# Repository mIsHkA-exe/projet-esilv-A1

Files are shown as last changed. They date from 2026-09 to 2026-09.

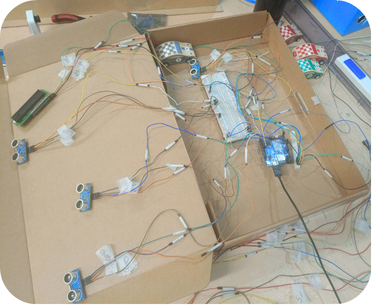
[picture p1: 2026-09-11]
images/wiring-prototype.png

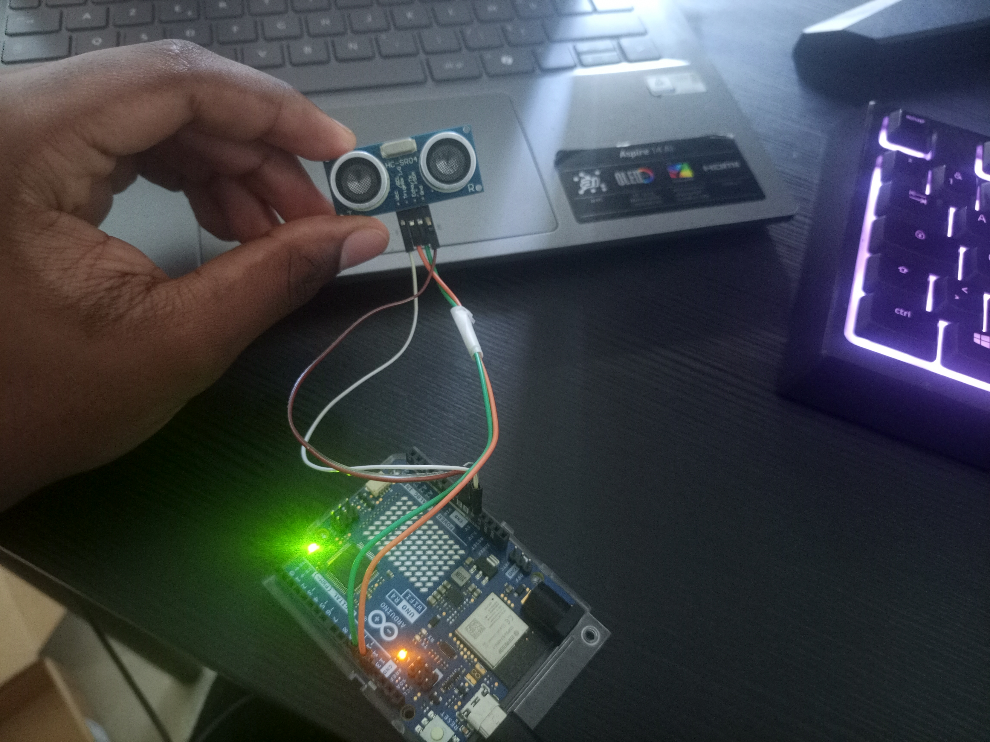
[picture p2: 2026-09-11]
unit-tests-iot/Ultrasons/Montage/Montage.jpg

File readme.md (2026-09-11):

# DAVINCI CUSTOM GARAGE — Smart Parking

> A connected smart parking system combining **web development, IoT, embedded systems, electronics, and real-time data synchronization**.







---

## Table of Contents

* [Project Overview](#project-overview)
* [Objectives](#objectives)
* [System Architecture](#system-architecture)
* [System Workflow](#system-workflow)
* [Web Application](#web-application)
* [Database](#database)
* [REST API](#rest-api)
* [Embedded System](#embedded-system)
* [QR-Code Access Control](#qr-code-access-control)
* [Parking-Space Detection](#parking-space-detection)
* [3D Modeling](#3d-modeling)
* [Simulation and Testing](#simulation-and-testing)
* [Development Challenges](#development-challenges)
* [Project Status](#project-status)
* [Contributions and Suggestions](#contributions-and-suggestions)
* [Budget](#budget)
* [Security and Privacy](#security-and-privacy)
* [Current Limitations](#current-limitations)
* [Future Improvements](#future-improvements)
* [Repository Structure](#repository-structure)
* [Technologies](#technologies)
* [Skills Demonstrated](#skills-demonstrated)
* [Team](#team)
* [Documentation](#documentation)
* [Conclusion](#conclusion)

---

## Project Overview

**DAVINCI CUSTOM GARAGE** is a connected smart parking prototype developed as part of the **Cybersecurity Bachelor's program at ESILV** during the 2025–2026 academic year.

The project combines a **web-based parking reservation platform** with an **automated physical model** representing a connected parking infrastructure.

The main objective is to connect a digital parking management platform with a physical embedded system in order to simulate automated parking management.

### Main Features

The platform allows users to:

* View available parking spaces.
* Reserve a parking space online.
* Receive a unique QR code.
* Use the QR code as an access credential.
* Automatically trigger the parking entrance barrier after validation.
* View parking availability through the web interface.
* Synchronize physical parking-space occupancy with the web application.

The physical prototype detects parking-space occupancy and communicates this information to the web application, allowing the digital and physical states of the parking system to remain synchronized.

---

## Objectives

The project was designed to address several challenges associated with urban parking management.

### Main Objectives

* Reduce the time required to find an available parking space.
* Improve the management of available parking areas.
* Automate access to the parking facility.
* Provide users with updated parking information.
* Synchronize physical infrastructure with a web application.
* Experiment with embedded systems and web technologies.
* Develop a connected system combining electronics, software, databases, and communication protocols.
* Respect a maximum hardware budget of **€150**.

The original project requirements also identified automatic vehicle detection, parking availability information, access control, continuous operation, low energy consumption, and maintainability as major service functions.

---

## System Architecture

The system is organized into three main layers:

```text
┌──────────────────────────────────────────────────┐
│                    USER LAYER                    │
│                                                  │
│          Web Interface / Reservation System      │
└────────────────────────┬─────────────────────────┘
                         │
                         ▼
┌──────────────────────────────────────────────────┐
│                APPLICATION LAYER                 │
│                                                  │
│       Symfony / REST API / Doctrine / MySQL      │
│                                                  │
│  • Users                                         │
│  • Reservations                                  │
│  • QR Codes                                      │
│  • Parking Spaces                                │
│  • Access History                                │
└────────────────────────┬─────────────────────────┘
                         │
                         │ JSON / API
                         ▼
┌──────────────────────────────────────────────────┐
│                 EMBEDDED LAYER                   │
│                                                  │
│          Arduino UNO R4 WiFi + ESP32-CAM         │
│                                                  │
│  • Ultrasonic Sensors                            │
│  • LEDs                                          │
│  • LCD Display                                   │
│  • Servo Motors                                  │
└────────────────────────┬─────────────────────────┘
                         │
                         ▼
                ┌─────────────────┐
                │ Physical Parking│
                └─────────────────┘
```

This architecture enables communication between the web platform and the physical prototype, allowing parking-space information to be transmitted and updated throughout the system.

---

## System Workflow

The general workflow is:

```text
User accesses the web application
              │
              ▼
Checks available parking spaces
              │
              ▼
Makes a reservation
              │
              ▼
System generates a unique QR code
              │
              ▼
User presents QR code at the entrance
              │
              ▼
ESP32-CAM reads the QR code
              │
              ▼
Symfony REST API validates the reservation
              │
        ┌─────┴─────┐
        │           │
      VALID       INVALID
        │           │
        ▼           ▼
 Open barrier   Access denied
        │
        ▼
Vehicle enters the parking
        │
        ▼
Sensor detects vehicle presence
        │
        ▼
Parking-space status is updated
        │
        ▼
Data is transmitted to the server
        │
        ▼
Web interface is updated
```

The objective is to maintain consistency between the physical state of the parking infrastructure and the information displayed on the web application.

---

## Web Application

The web application was developed using the **Symfony PHP framework** and follows an **MVC architecture**.

### Main Features

* Parking-space availability display.
* Online parking reservation.
* Automatic QR-code generation.
* User account management.
* Administration interface.
* Parking-space status management.
* Communication with the embedded infrastructure.
* Real-time synchronization between the physical model and the web platform.

The web application acts as the main digital interface between users and the smart parking system.

---

## Database

The project uses a relational database managed with **MySQL** and **Doctrine ORM**.

The database centralizes the information required for the operation of the system.

### Main Entities

```text
User
 │
 ├── Reservation
 │      │
 │      └── QR Code
 │
 └── Access History

Parking Space
 │
 └── Availability Status
```

### Main Data Categories

* Users
* Reservations
* Parking spaces
* QR codes
* Parking-space status
* Access history

For the academic prototype, fictitious data is used for demonstrations. No real banking information is intended to be stored.

---

## REST API

A **REST API developed with Symfony** provides communication between the web platform and the physical parking prototype.

The API uses **JSON** for data exchange.

### Main Responsibilities

* Validate QR codes.
* Retrieve parking-space status.
* Update parking-space occupancy.
* Receive events generated by the Arduino system.
* Synchronize physical events with the database.
* Provide updated information to the web application.

The API acts as the communication bridge between the embedded system and the application layer.

### Communication Flow

```text
Embedded System
       │
       │ HTTP / JSON
       ▼
Symfony REST API
       │
       ├── QR Code Validation
       │
       ├── Parking Status
       │
       ├── Occupancy Updates
       │
       └── Embedded Events
       │
       ▼
Database
       │
       ▼
Web Application
```

---

## Embedded System

The physical prototype is built around several electronic components.

| Component | Purpose |
| --- | --- |
| **Arduino UNO R4 WiFi** | Main embedded controller |
| **ESP32-CAM** | QR-code reading and recognition |
| **HC-SR04 ultrasonic sensors** | Vehicle presence detection |
| **Infrared sensors** | Entrance and exit detection |
| **Servo motors** | Automated parking barriers |
| **LEDs** | Parking-space status indication |
| **LCD 16x2** | Parking information display |
| **RGB LED strip** | Parking model lighting |
| **Breadboard** | Component integration |
| **Jumper wires** | Electrical connections |

The embedded software is developed using **Arduino IDE and C++**.

---

## QR-Code Access Control

QR-code validation is one of the main access-control mechanisms implemented in the project.

```text
Web Reservation
       │
       ▼
Unique QR Code
       │
       ▼
ESP32-CAM
       │
       ▼
QR Code Recognition
       │
       ▼
Symfony REST API
       │
       ▼
Reservation Validation
       │
   ┌───┴────┐
   │        │
 VALID    INVALID
   │        │
   ▼        ▼
Open     Reject
Barrier  Access
   │
   ▼
Record Access
```

When a valid QR code is detected, the system authorizes access and triggers the opening of the parking barrier.

Invalid QR codes are rejected.

The access event can then be recorded in the database.

---

## Parking-Space Detection

Each parking space is equipped with a sensor designed to detect whether a vehicle is present.

When a vehicle is detected:

1. The physical state of the parking space changes.
2. The corresponding LED indicates the state of the space.
3. The embedded system processes the information.
4. The information is transmitted through the communication layer.
5. The database is updated.
6. The web interface can reflect the new parking status.

The tests conducted during the project demonstrated that the detection mechanism was sufficiently reliable for the scale of the prototype.

---

## 3D Modeling

Before the physical assembly of the prototype, the parking structure was modeled using **SolidWorks**.

The 3D modeling phase was used to design and organize:

* Parking spaces.
* Traffic lanes.
* Entrance and exit barriers.
* Sensor locations.
* Electronic component supports.
* Cable-management structures.
* Protective covers for electronic connections.

The covers were designed to improve the appearance of the prototype while protecting and organizing the wiring.

---

## Simulation and Testing

Several tools were used to validate the system before and during physical implementation.

### Simulation Tools

* **Wokwi**
* **Tinkercad**

These platforms were used to simulate electronic components and validate circuit behavior before working with the physical hardware.

### Physical Testing

The following components were tested:

* Ultrasonic sensors
* Infrared sensors
* LEDs
* Servo motors
* LCD display
* ESP32-CAM
* Arduino UNO R4 WiFi

### Functional Tests

| Test | Result |
| --- | --- |
| Vehicle detection | Successful |
| Parking-space status update | Successful |
| Valid QR-code recognition | Successful |
| Invalid QR-code rejection | Successful |
| Automatic barrier opening | Successful |
| Automatic barrier closing | Successful |
| Database synchronization | Successful |
| Web interface synchronization | Successful |
| Web ↔ Embedded communication  | Functional |

The tests demonstrated that the main components of the prototype could communicate and operate together according to the project's objectives.

---

## Development Challenges

The development of **DAVINCI CUSTOM GARAGE** involved several technical challenges.

One of the main difficulties was implementing reliable **real-time parking-space display and synchronization** between the physical prototype and the web application.

### Symfony ↔ Arduino Synchronization

The communication between the Symfony application, REST API, and Arduino embedded system required several development and testing phases.

Particular difficulties were encountered in:

* Transmitting information between the web application and the embedded system.
* Synchronizing the actual state of parking spaces with the information displayed on the website.
* Updating parking availability in real time.
* Maintaining consistency between the database, Symfony, and Arduino.
* Handling events generated by physical sensors.
* Managing communication between multiple hardware and software components.

### Real-Time Parking Display

The expected communication chain was:

```text
Parking Sensors
       │
       ▼
Arduino
       │
       ▼
Communication Layer
       │
       ▼
Symfony REST API
       │
       ▼
Database
       │
       ▼
Web Interface
```

Maintaining synchronization throughout this entire chain proved to be one of the more challenging aspects of the project.

Although the prototype demonstrates the overall concept, this part of the system remains an important area for future improvement.

---

## Project Status

**DAVINCI CUSTOM GARAGE** is an evolving academic project.

The current version demonstrates the main concept of a connected smart parking system, but several technical aspects can still be improved.

### Planned Improvements

* Improve Symfony-to-Arduino communication.
* Optimize the REST API.
* Improve real-time data synchronization.
* Reduce synchronization delays.
* Improve code structure and maintainability.
* Improve database management.
* Strengthen system reliability.
* Improve UI/UX.
* Add new platform features.
* Improve the overall user experience.

The project should therefore be considered an **active prototype rather than a final production-ready solution**.

---

## Contributions and Suggestions

We are open to suggestions and ideas that could help improve the project.

We particularly welcome proposals related to:

* Code optimization
* Software architecture
* API design
* Symfony development
* Arduino communication
* Real-time data management
* Database optimization
* Cybersecurity
* UI/UX improvements
* User experience
* Embedded-system optimization
* New features and functionalities

If you have an idea that could improve the project, feel free to open an **Issue** or submit a **Pull Request**.

Any constructive contribution aimed at improving the code, reliability, architecture, security, or user experience is welcome.

---

## Budget

The project was developed under a strict hardware budget constraint of **€150**.

### Final Hardware Budget

| Category  | Amount |
| --- | ---: |
| **Total** | **€142.74 including VAT** |

The hardware components included:

* Arduino board
* ESP32-CAM
* Ultrasonic sensors
* Infrared sensors
* Servo motor
* LEDs
* LCD display
* Breadboard
* Jumper wires
* RGB LED strip

The project therefore remained within the defined budget constraint.

---

## Security and Privacy

Because this project was developed as part of a **Cybersecurity Bachelor's program**, security and data protection were considered during the design process.

### Security and Privacy Considerations

* Use of fictitious data for demonstrations.
* No real banking information.
* Consideration of GDPR requirements.
* Consideration of CNIL recommendations.
* Server-side validation of QR-code access.
* Controlled access to the physical parking.
* Centralized management of reservations and access information.

The project documentation also identifies electrical safety and applicable infrastructure regulations as important constraints for a real-world implementation.

---

## Current Limitations

Several limitations remain in the current prototype:

* Sensor accuracy can be affected by vehicle positioning and environmental conditions.
* The prototype operates at a small physical scale.
* QR-code recognition depends on lighting conditions and camera distance.
* The architecture has not yet been tested with a large number of simultaneous users.
* Real-world network availability requirements have not been fully addressed.
* The current real-time synchronization mechanism still requires optimization.
* Communication between the embedded system and the web application can be further improved.
* The current UI can be enhanced to provide a better user experience.

These limitations provide several opportunities for future development.

---

## Future Improvements

### Artificial Intelligence

AI-based algorithms could be integrated to predict parking occupancy and optimize the allocation of available spaces.

### Automatic License Plate Recognition

License-plate recognition could complement or eventually replace QR-code-based access control.

### Mobile Application

A dedicated mobile application could provide users with easier access to reservations and real-time parking availability.

### Cloud Infrastructure

Cloud-based services could improve scalability, availability, monitoring, and remote management.

### Automated Payments

A secure automated payment system could bring the prototype closer to a real-world commercial parking solution.

### Advanced Monitoring

Additional monitoring and analytics could be implemented to provide administrators with detailed information about parking usage and system performance.

---

## Repository Structure

The recommended repository structure is:

```text
davinci-custom-garage/
│
├── README.md
│
├── web/
│   ├── src/
│   ├── templates/
│   ├── config/
│   └── ...
│
├── api/
│   └── ...
│
├── embedded/
│   ├── arduino/
│   └── esp32-cam/
│
├── database/
│   └── ...
│
├── hardware/
│   ├── schematics/
│   └── components/
│
├── 3D/
│   └── solidworks/
│
├── simulation/
│   ├── wokwi/
│   └── tinkercad/
│
├── documentation/
│   ├── cahier-des-charges/
│   └── rapport/
│
└── assets/
    ├── images/
    └── diagrams/
```

---

## Technologies

### Software

* PHP
* Symfony
* Doctrine ORM
* MySQL
* SQL
* REST API
* JSON
* C++
* Arduino IDE
* Python

### Hardware

* Arduino UNO R4 WiFi
* ESP32-CAM
* HC-SR04 ultrasonic sensors
* Infrared sensors
* Servo motors
* LEDs
* LCD 16x2
* RGB LED strip
* Breadboard
* Jumper wires

### Design and Simulation

* SolidWorks
* Wokwi
* Tinkercad

---

## Skills Demonstrated

This project provided practical experience in several technical areas:

* Web application development
* PHP and Symfony development
* REST API development
* Relational database design
* SQL and Doctrine ORM
* Embedded programming
* C++ programming
* Arduino development
* ESP32 integration
* Sensor integration
* Electronic circuit design
* Real-time communication
* QR-code-based access control
* System integration
* 3D modeling
* Hardware simulation
* Technical testing
* Debugging and troubleshooting
* Team collaboration
* Project management

---

## Team

### Team 108 — ESILV

* **Kyllian Siewe Tiague**
* **Vikash Srikanthan**
* **Abdulrahman El Najjar**
* **Adam Tiss**

**Academic project developed as part of the Cybersecurity Bachelor's program at ESILV, 2025–2026.**

---

## Documentation

The project documentation includes:

* Project requirements specification
* Functional analysis
* Technical analysis
* Structural analysis
* Hardware component documentation
* Purchase order and budget documentation
* Web application documentation
* Embedded-system documentation
* Database documentation
* Testing and validation results
* Project development report

---

## Conclusion

**DAVINCI CUSTOM GARAGE** is an academic prototype demonstrating how **web technologies, embedded systems, electronics, databases, and connected infrastructure** can be combined to create a smart parking solution.

The project implements several key concepts:

* Online parking reservation
* QR-code-based access control
* Automated barriers
* Vehicle detection
* Parking-space monitoring
* REST API communication
* Database synchronization
* Web-to-hardware communication
* Real-time parking information

The project also provided practical experience in identifying and solving integration problems between software and hardware components.

Although several aspects of the system still require optimization — particularly **real-time display and synchronization between Symfony and the Arduino-based infrastructure** — the project provides a functional foundation for future development.

The team intends to continue improving the code, communication architecture, system reliability, and UI/UX.

**DAVINCI CUSTOM GARAGE is therefore not considered a finished product, but an evolving prototype open to optimization, experimentation, and future contributions.**

---

## Academic Project

**DAVINCI CUSTOM GARAGE — Smart Parking**

**ESILV — Cybersecurity Bachelor's Program**

**Academic Year 2025–2026**

**Team 108**

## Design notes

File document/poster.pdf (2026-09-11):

# DAVINCI CUSTOM GARAGE

LE FUTUR DU STATIONNEMENT INTELLIGENT

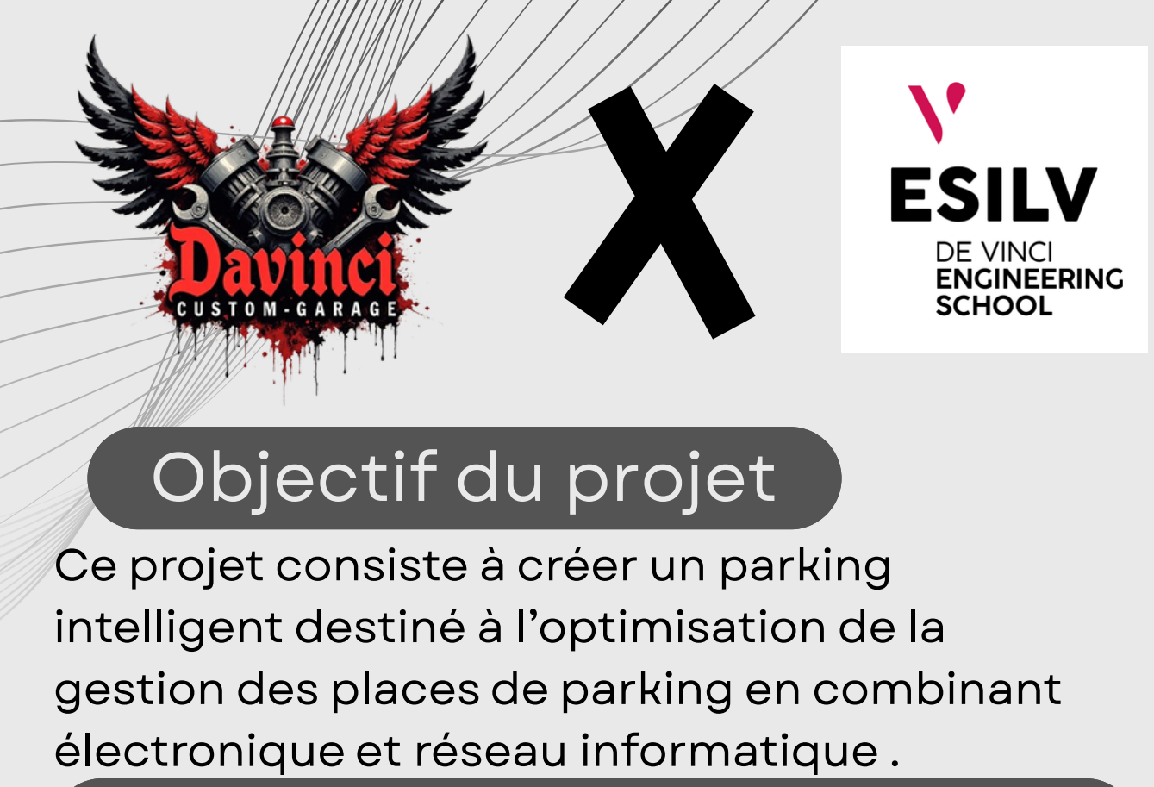
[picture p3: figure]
Objectif du projet; Ce projet consiste à créer un parking; électronique et réseau informatique .

intelligent destiné à l’optimisation de la gestion des places de parking en combinant

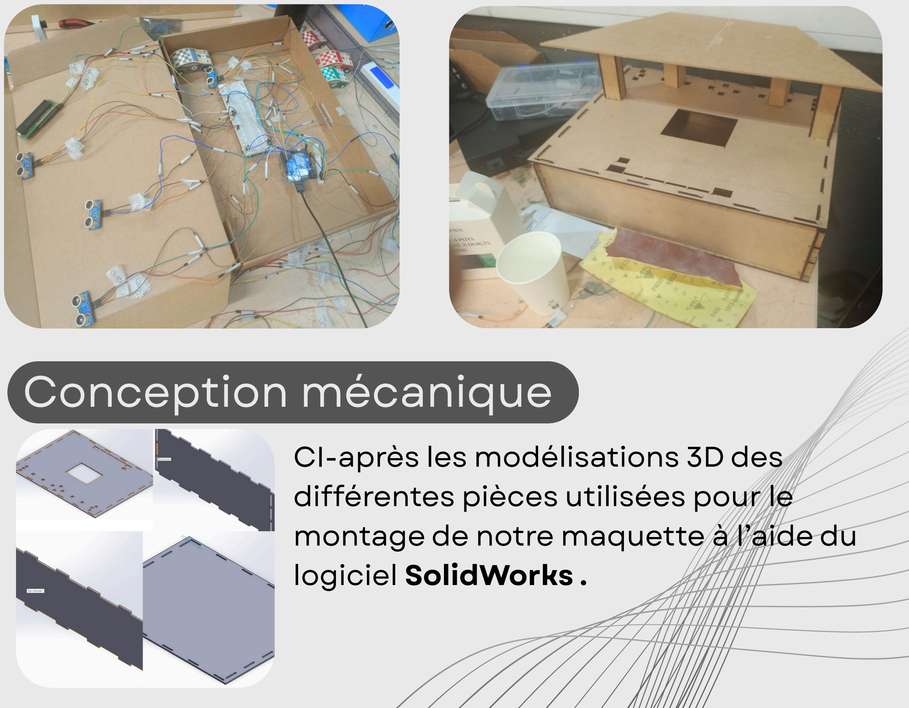
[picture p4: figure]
Conception mécanique; CI-après les modélisations 3D des différentes pièces utilisées pour le montage de notre maquette à l’aide du logiciel SolidWorks .

## Objectif du projet

## Etude du cahier des charges

Il s’agit dans ce projet de concevoir un dispositif opérationel en fonction des beoins fonctionnels et des contraintes techniques imposées avec un budget de 150 euros .

## Simulation électronique & Prototype

Simulation de la détection des places avec les
capteurs à ultrasons et impression du prototype

## Contribution individuelle

SieweTiague Kyllian : conception mécanique , réalisation des prototypes et maintenance logiciel
Srikanthan Vikash : Gestion de la décoration de la maquette et de la rédaction des documents de synthèse El Najjar Abdulrahman : Réalisation du poster et contribution à la réalisation de la maquete
Tiss Adam : Contribution à la réalisation de la maquette et aux tests des systèmes .

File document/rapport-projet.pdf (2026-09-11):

# Rapport de Projet : Conception et Réalisation d'un Système de Stationnement Intelligent Connecté

Membre de l’équipe :

Nom | Prenom
Siewe Tiague | Kyllian
Srikanthan | Vikash
El Najjar | Abdulrahman
Tiss | Adam

Sommaire :

Les études sur la mobilité urbaine montrent qu’un conducteur peut consacrer entre 10 et 20 minutes à la recherche d’une place de stationnement en zone urbaine dense. À l’échelle annuelle, cette perte de temps représente plusieurs dizaines d’heures improductives

I - INTRODUCTION GÉNÉRALE

### 1.1 Cadre et contexte académique

Dans le cadre de notre cursus Bachelor en Cybersécurité pour l’année académique 2025–2026 à l’ESILV, nous avons été amenés à concevoir un système de stationnement intelligent combinant électronique analogique et numérique, systèmes embarqués et développement web pour la gestion automatisée d’un parking connecté.

Ce projet pédagogique s’inscrit dans une démarche disciplinaire mobilisant des compétences en programmation, réseaux, cybersécurité, bases de données et électronique embarquée. L’objectif principal consiste à développer, dans un délai défini, une solution autonome capable d’assurer une communication en temps réel entre une infrastructure physique intelligente et une plateforme web de gestion.

Au-delà de l’aspect technique, ce projet vise également à nous confronter aux problématiques concrètes liées à la conception de systèmes connectés, notamment en matière d’automatisation, de gestion des données, de sécurité des accès et d’optimisation des infrastructures urbaines.

### 1.2 La problématique sociale et environnementale

L’évolution démographique et l’urbanisation croissante des grandes métropoles s’accompagnent d’une augmentation constante du trafic automobile mondial. Dans ce contexte, la gestion des infrastructures de stationnement représente aujourd’hui un enjeu majeur pour les collectivités et les usagers.

Trouver une place de parking disponible est devenu une source urbaine importante .Dans les zones fortement fréquentées, les automobilistes passent plusieurs minutes à circuler à faible vitesse dans le seul but de rechercher un emplacement libre. Cette situation engendre de nombreuses conséquences à la fois économiques, environnementales et sociétales.

Perte de temps
Les études sur la mobilité urbaine montrent qu’un conducteur peut consacrer entre 10 et 20 minutes à la recherche d’une place de stationnement en zone urbaine dense. À l’échelle annuelle, cette perte de temps représente plusieurs dizaines d’heures improductives pour un usager régulier.

Impact environnemental
La circulation répétitive des véhicules à faible allure provoque une surconsommation importante de carburant. Les nombreux arrêts, redémarrages et ralentissements entraînent une augmentation significative des émissions de gaz à effet de serre, notamment du dioxyde de carbone (CO₂). À grande échelle, ce phénomène contribue directement à la pollution atmosphérique et à la dégradation de l’environnement urbain.

Impact sociétal
La difficulté à trouver rapidement une place de stationnement constitue également une source récurrente de stress, de frustration et de fatigue pour les conducteurs. Cette problématique affecte la qualité de vie des usagers et participe à la saturation générale des centres urbains.

Face à ces constats, le développement de solutions de stationnement intelligentes apparaît comme une réponse technologique pertinente permettant d’améliorer la fluidité urbaine, de réduire les émissions polluantes et d’optimiser l’utilisation des espaces disponibles.

### 1.3 L'approche globale : DAVINCI CUSTOM GARAGE (Notre parking)

Pour répondre à cette problématique,nous avons imaginé une solution globale et intelligente découpée en deux piliers technologiques majeurs en parfaite synergie :

- L'interface logicielle (Le Site Web) : Développée à l'aide du framework PHP Symfony, cette plateforme permet aux clients d'anticiper leur déplacement. L'utilisateur peut vérifier la disponibilité et effectuer une réservation en ligne. Le système génère alors un QR code unique, tracé et sécurisé dans une base de données, qui servira de droit d'accès physique.
- L'infrastructure physique (La Maquette Connectée) : Afin de matérialiser visuellement notre concept, nous concevons une maquette automatisée à partir d'un microcontrôleur Arduino R4 et d'un module ESP32-CAM. Ce système gère l'accueil des véhicules par lecture du QR code, l'ouverture automatisée des barrières, et s'appuie sur des capteurs embarqués pour surveiller en temps réel l'occupation des places de stationnement. Toute modification physique de l'état d'une place met instantanément à jour la base de données du site web.

II - CAHIER DES CHARGES

### 2.1 Périmètre et Objectifs du Système

Le projet a pour objectif de concevoir et de réaliser un prototype fonctionnel de stationnement intelligent. Le périmètre de cette étude s'articule autour de trois axes interconnectés :

- L'application Web de gestion : Une interface utilisateur permettant la consultation en temps réel de la disponibilité des places et la réservation à distance, complétée par une interface d'administration pour la supervision globale des données.
- La maquette physique : Une infrastructure miniature automatisée simulant l'accès physique, le contrôle des barrières et la surveillance des emplacements.
- La passerelle de communication : Un système d'échange bidirectionnel en temps réel permettant à la maquette de mettre à jour la base de données centrale dès qu'un changement d'état physique survient sur une place.

### 2.2 Analyse des Besoins (Besoins Fonctionnels)

Pour répondre efficacement aux attentes des usagers et des administrateurs, le système doit couvrir les besoins fonctionnels suivants :

- Réservation et sécurisation des accès : L'utilisateur doit pouvoir réserver sa place en ligne et obtenir un QR code unique et sécurisé (généré via Symfony). Ce code sert de droit d'accès exclusif à l'entrée du parking.
- Contrôle automatisé des flux : À l'entrée, le module ESP32-CAM doit lire et valider le QR code afin de déclencher automatiquement l'ouverture de la barrière via un servomoteur.
- Détection autonome de présence : Chaque place du parking doit être équipée de capteurs (infrarouges ou ultrasoniques) capables de détecter de manière continue et autonome l'occupation d'un emplacement par un véhicule.
- Signalisation visuelle locale : Le système doit guider visuellement l'usager dans la maquette grâce à des indicateurs lumineux (une LED s'allume pour indiquer qu'une place est occupée) et un écran LCD affichant un message d'accueil ou le nombre de places restantes.
- Actualisation en temps réel : L'état de disponibilité des places (libre/occupée) doit être synchronisé instantanément avec la base de données pour être consultable sur le site internet.

### 2.3 Contraintes du Projet

La conception de la solution DAVINCI CUSTOM GARAGE est soumise à plusieurs exigences et restrictions strictes :

- Contraintes Économiques (Budget) : Le coût global pour l'achat des composants matériels de la maquette (carte Arduino R4, module ESP32-CAM, capteurs, actionneurs) est strictement limité à un budget maximal de 150 €. Cela impose une sélection rigoureuse de composants à la fois économiques, fiables et optimisés.
- Contraintes Techniques et Matérielles : L'architecture matérielle repose obligatoirement sur l'utilisation d'une carte microcontrôleur principale Arduino R4 WiFi et d'un module ESP32-CAM pour la brique de vision. L'ensemble des développements embarqués doit être réalisé via l'IDE Arduino.
- Contraintes Logicielles : La plateforme web de gestion et l'API de communication doivent être exclusivement développées avec le framework PHP Symfony, en exploitant l'ORM Doctrine et le langage SQL pour la persistance des données.
- Contraintes de Sécurité et Confidentialité (RGPD) : S'agissant d'un projet académique en Cybersécurité, aucune donnée bancaire ou personnelle réelle ne doit être stockée. Le système doit utiliser des outils de génération de données fictives (Fakers) pour simuler les transactions et les profils d'utilisateurs en toute sécurité.
- Contraintes de Fiabilité et Performance : Le traitement des informations et la détection doivent être rapides et précis afin d'éviter tout blocage des barrières ou toute divergence d'information entre la maquette et l'interface Web.

### 2.4 Caractérisation des Fonctions de Service

Pour guider la phase de développement, les fonctions de service du projet ont été hiérarchisées selon leur niveau de priorité:

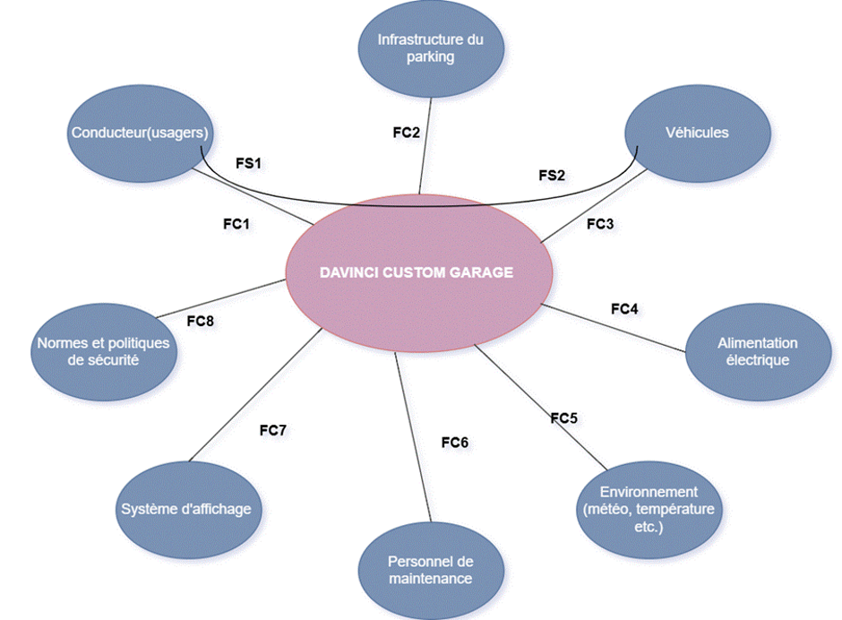
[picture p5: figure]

Figure 2.4 : Caractérisation des fonctions de services
III - CONCEPTION DE LA SOLUTION

### 3.1 Architecture Générale du Système

La solution DAVINCI CUSTOM GARAGE repose sur une architecture hybride associant une infrastructure physique électronique et une plateforme web. L'ensemble des composants communiquent afin de garantir une gestion automatisée et synchronisée du stationnement.

Code | Fonction de Service
FP1 | Détecter automatiquement la présence des véhicules sur les places
FP2 | Informer les usagers sur l’état des places disponibles (Web/LCD)
FP3 | Sécuriser et contrôler l'accès à l'entrée (Validation du QR code)
FP4 | Assurer le fonctionnement en continu et la fiabilité des alertes
FP5 | Guider les usagers vers une place libre (Signalisation par LED)
FP6 | Optimiser la consommation énergétique des composants électroniques
FP7 | Permettre une maintenance simple et une modularité du câblage

Le système est composé de trois couches principales :

- La couche utilisateur : constituée du site web développé sous Symfony, elle permet aux clients de consulter les disponibilités du parking, de réserver une place et de recevoir un qr code unique.
- La couche applicative : représentée par le serveur web et la base de données. Cette couche assure le stockage des réservations, la gestion des utilisateurs, la génération des qr codes ainsi que la synchronisation des informations provenant des cartes électroniques de la maquette .
- La couche embarquée : composée de la carte Arduino UNO R4 WiFi, des modules ESP32-CAM, des capteurs de présence, des LEDs, de l'écran LCD et des servomoteurs. Cette couche gère les interactions physiques avec les véhicules et transmet les données vers le serveur.

Le principe de fonctionnement repose sur un échange permanent d'informations entre la maquette et l'application web afin de garantir une cohérence en temps réel des données de stationnement.

### 3.2 Description de l'Architecture Matérielle

L'infrastructure physique du parking intelligent est conçue autour de plusieurs composants électroniques complémentaires notamment :

→ Arduino UNO R4 WiFi
La carte Arduino UNO R4 WiFi constitue le cœur du système embarqué. Elle assure la collecte des données provenant des capteurs, le pilotage des actionneurs et la communication avec le serveur distant via le réseau Wi-Fi.

→ ESP32-CAM

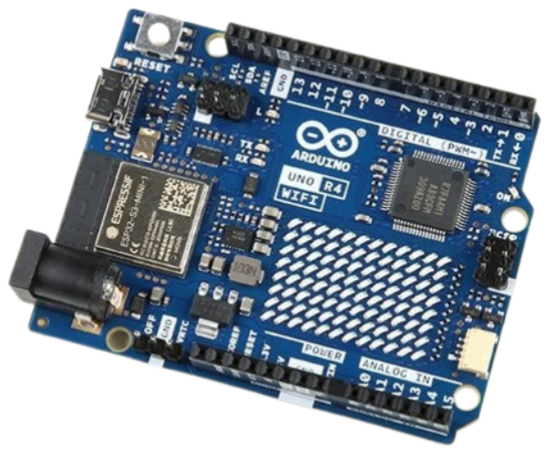
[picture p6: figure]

Le module ESP32-CAM est chargé de la lecture et de la reconnaissance des QR codes présentés à l'entrée du parking. Après validation du code auprès de la base de données, il autorise ou refuse l'accès au véhicule. Un autre module ESP32 est utilisé pour la gestion des actionneurs de manière générale .

→ Capteurs de présence

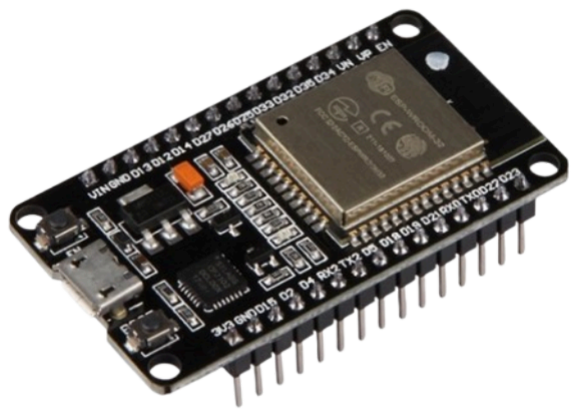
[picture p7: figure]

Chaque place de stationnement est équipée d'un capteur ultrason permettant de détecter la présence ou l'absence d'un véhicule. Ces informations sont transmises à l'Arduino afin de mettre à jour l'état des places.

→ Servomoteurs
Les servomoteurs simulent les barrières d'entrée et de sortie du parking. Leur ouverture est déclenchée automatiquement lorsqu'un QR code valide est détecté.

→ Écran LCD
L'écran LCD affiche différentes informations utiles aux utilisateurs, notamment le nombre de places disponibles ainsi que des messages de bienvenue .

→ LED de signalisation

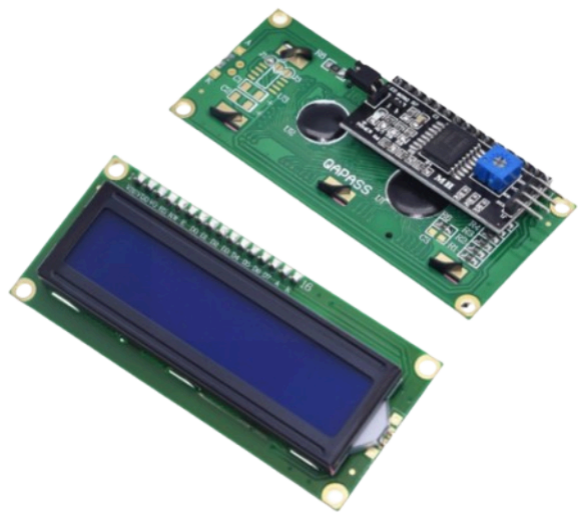
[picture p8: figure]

Des LEDs permettent de représenter visuellement l'état des places de stationnement. On a utilisé un code couleur composé de 3 couleurs qui permettent de distinguer visuellement l’état des places .

### 3.3 Description de l'Architecture Logicielle

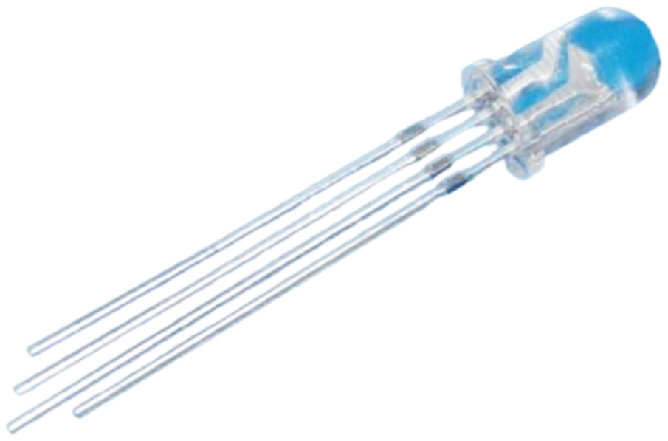
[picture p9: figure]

Le développement logiciel repose sur plusieurs technologies complémentaires . Il s’agit principalement de :

→ Framework Symfony
Symfony a été retenu pour développer l'ensemble de l'application web. C’est un FrameWork PHP qui permet la gestion de l'architecture MVC de toute l’application Web avec la manipulation de Doctrine , Composer et bien d’autres librairies .

→ Base de données
La persistance des données est assurée par une base de données relationnelle gérée via Doctrine ORM et alimenté par Sql . Les principales informations stockées concernent :
- Les utilisateurs
- Les réservations
- Les QR codes générés
- L'état des places de stationnement
- Les historiques d'accès
- Les places

### 3.4 Diagramme Fonctionnel du Système

Le fonctionnement global du système peut être résumé selon les étapes suivantes :

1. L'utilisateur consulte les places disponibles sur le site web.
2. Il effectue une réservation.
3. Le système génère un QR code unique.
4. À l'arrivée du véhicule, l'ESP32-CAM scanne le QR code.
5. Le serveur vérifie la validité de la réservation.
6. Si la réservation est valide, la barrière s'ouvre automatiquement.
7. Le véhicule se gare sur une place disponible.
8. Le capteur détecte l'occupation de la place.
9. L'information est transmise à la base de données.
10.Le site web met à jour instantanément le nombre de places disponibles.

Cette architecture garantit une gestion automatisée, sécurisée et temps réel de l'ensemble du parking connecté.

IV - RÉALISATION ET DÉVELOPPEMENT

### 4.1 Développement de l'interface web

L'interface web constitue le point central d'interaction entre les utilisateurs et le système de stationnement intelligent DAVINCI CUSTOM GARAGE. Son développement a été réalisé à l'aide du framework Symfony. L'application permet aux utilisateurs de consulter en temps réel la disponibilité des places de stationnement, d'effectuer une réservation et d'obtenir un QR code servant de moyen d'identification lors de l'accès au parking.
L'architecture du projet suit le modèle MVC (Modèle - Vue - Controller), permettant une séparation claire entre la logique métier, les données et l'interface utilisateur.

Les principales fonctionnalités développées sont :

- Consultation des places disponibles
- Réservation d'une place de stationnement
- Génération automatique de QR codes
- Gestion des comptes utilisateurs
- Interface d'administration
- Affichage en temps réel de l'état du parking.

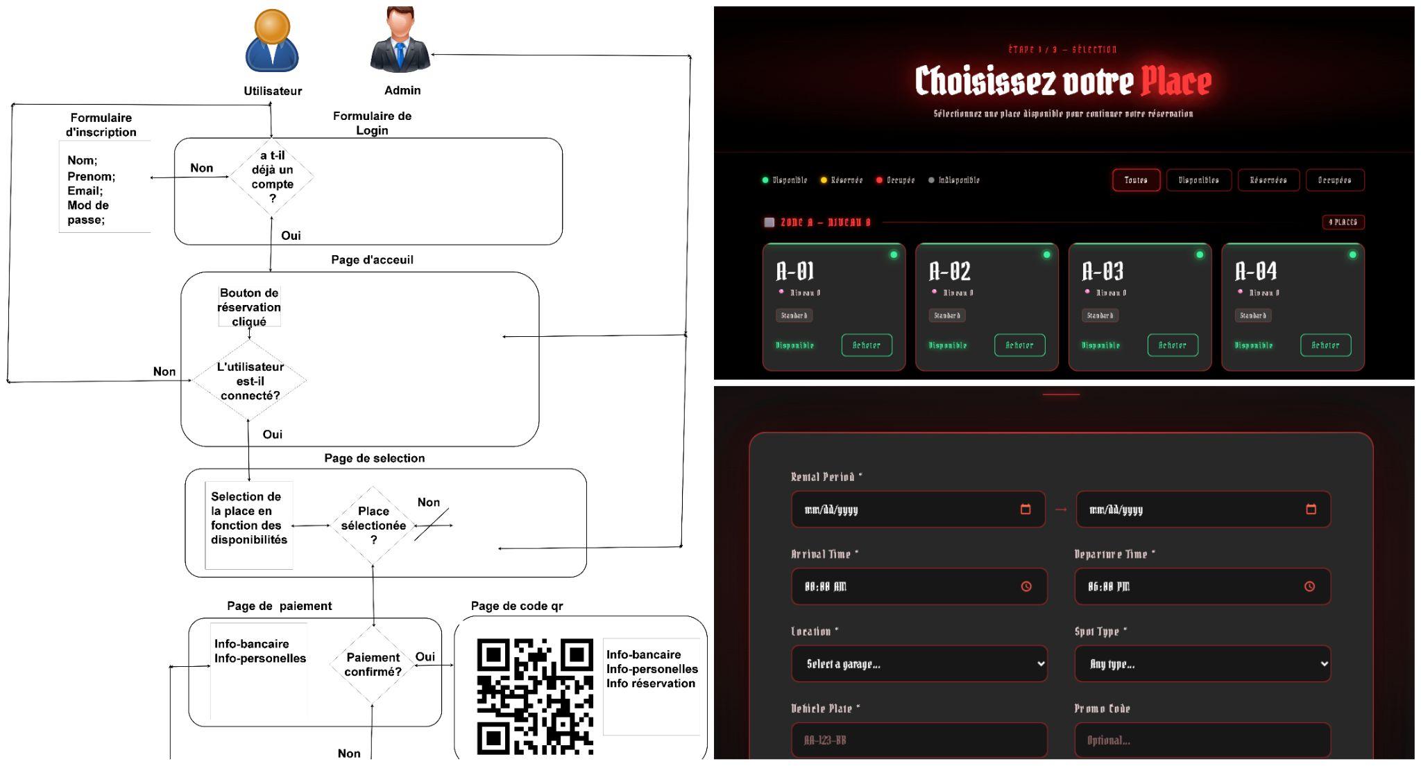
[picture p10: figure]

Figure 4.1 : capture Symfony de l’interface Web de réservation

### 4.2 Mise en place de la base de données

Afin d'assurer la gestion des informations du système, une base de données relationnelle a été mise en place à l'aide de MySQL et administrée via Doctrine ORM.Cette base de données centralise l'ensemble des informations nécessaires au fonctionnement du parking connecté.
Les principales entités implémentées sont :

Utilisateurs
Cette table contient les informations relatives aux utilisateurs enregistrés sur la plateforme :
- Identifiant unique
- Nom
- Adresse électronique
- Mot de passe sécurisé
- Rôle utilisateur

Réservations

Cette table stocke les réservations effectuées par les utilisateurs :

- Identifiant de réservation
- Utilisateur associé
- Place réservée
- Date et heure
- Statut de réservation

Places
Cette entité représente les emplacements disponibles dans le parking :
- Numéro de place
- État (libre ou occupée)

QR Codes
Chaque réservation génère un QR code unique permettant l'accès au parking et les informations enregistrées comprennent :
- Identifiant du QR code
- Réservation associée
- Date de création
- Statut de validité

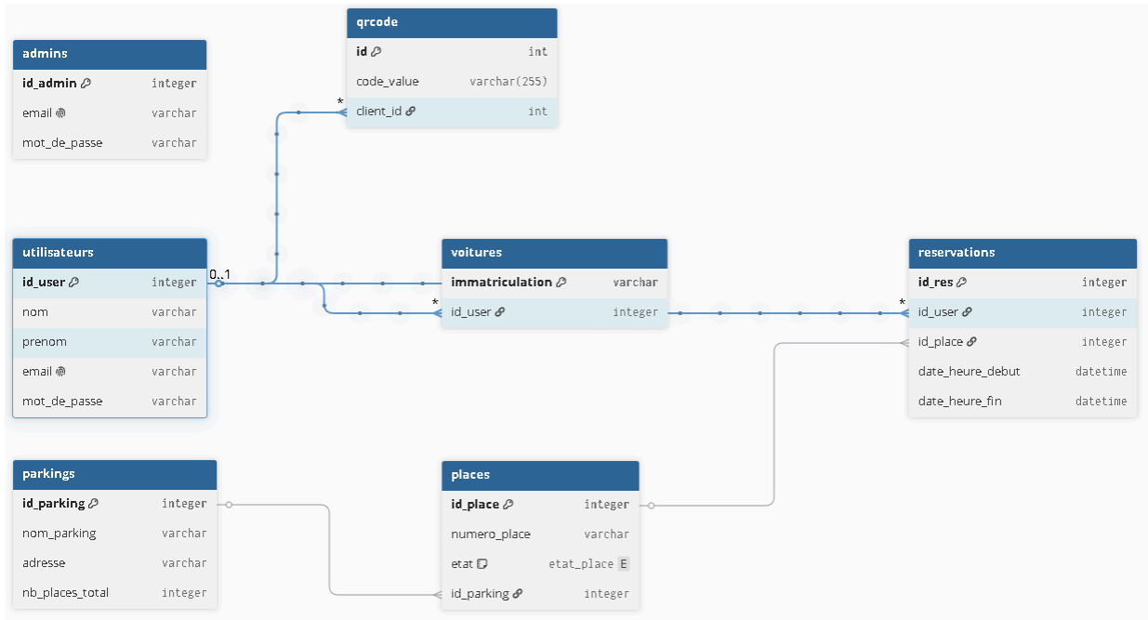
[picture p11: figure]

Figure 4.2 : Captures d’écran du diagramme Entités/Association de la base de données

### 4.3 Développement de l'API de Communication entre Symfony et le parking

Afin de permettre les échanges entre la maquette physique et l'application web, une API REST a été développée sous Symfony. Cette API joue un rôle essentiel dans la synchronisation des informations entre les composants matériels et la plateforme de gestion.
Les principales opérations réalisées par l'API sont :
- Vérification de la validité d'un QR code ;
- Consultation de l'état des places ;
- Mise à jour de l'occupation des emplacements ;
- Transmission des événements provenant de l'Arduino ;
- Actualisation des données affichées sur le site web.

Les échanges sont réalisés au format JSON afin de garantir une communication légère, rapide et compatible avec les systèmes embarqués.

### 4.4 Réalisation de la partie embarquée

La partie embarquée repose sur une carte Arduino UNO R4 WiFi associée à d’autres cartes électroniques notamment deux ESP32 L'Arduino assure la gestion des capteurs, des actionneurs et des communications avec le serveur distant.
Le programme embarqué a été développé à l'aide de l'environnement Arduino IDE en langage C++.

Les principales fonctions implémentées sont :

- Lecture des capteurs de présence (Capteur à ultrason HC-SR04)
- Gestion des LED de signalisation
- Contrôle des servomoteurs
- Affichage des informations sur l'écran LCD
- Synchronisation avec la base de données.

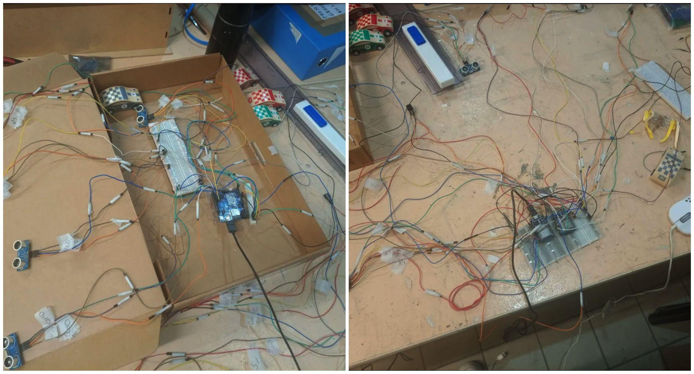
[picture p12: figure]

Figure 4.1 : Câblage des composants sur la carte Arduino

### 4.5 Intégration du Module ESP32-CAM

Le module ESP32-CAM est chargé de la lecture et de la reconnaissance des QR codes utilisés pour le contrôle d'accès. Lorsqu'un utilisateur présente son QR code à l'entrée du parking, l'image est analysée par le un script python qui extrait les informations nécessaires à l'identification de la réservation.
Le code décodé est ensuite ensuite transféré au serveur Symfony pour par une méthode POST pour passer à la vérification

Si la réservation est valide :

- la barrière s'ouvre automatiquement
- l'accès est enregistré dans la base de données
- l'utilisateur est autorisé à stationner

Dans le cas contraire, l'accès est refusé et un message d'erreur est affiché.

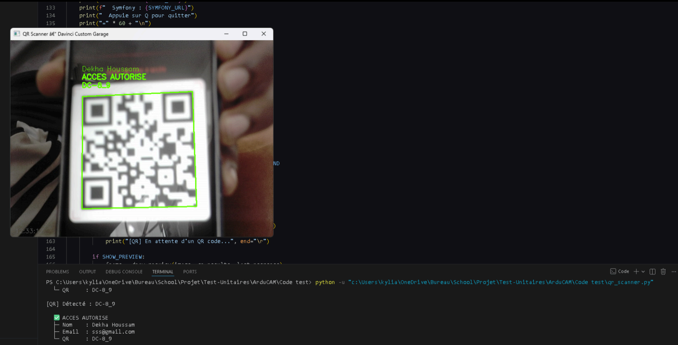
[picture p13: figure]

Figure 4.5 : Lecture de code qr par la ArduCam

### 4.6 Modélisation 3D de la Maquette

Avant la phase de fabrication et d'assemblage, une étape de modélisation 3D a été réalisée afin de concevoir la structure physique du parking intelligent. Cette démarche a permis de visualiser l'organisation générale du système, d'anticiper l'intégration des différents composants électroniques et d'optimiser l'agencement de la maquette.

La modélisation a été effectuée à l'aide d'un logiciel de conception SolidWorks. Elle a permis de représenter les caches des différents éléments constituant le parking, notamment les voies de circulation, les places de stationnement, les barrières d'accès, les emplacements des capteurs ainsi que les supports destinés aux cartes électroniques.

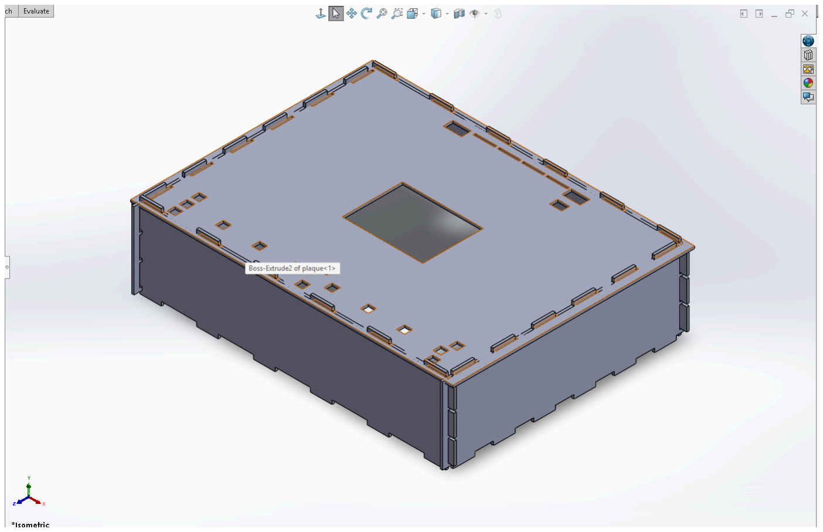
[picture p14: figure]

Figure 4.6 : Modélisation 3D complète du parking intelligent DAVINCI CUSTOM GARAGE

Dans le cadre de la réalisation de la maquette, plusieurs caches ont été modélisées en 3D afin de dissimuler les câbles reliant les capteurs aux cartes électroniques. Cette démarche avait pour objectif d'améliorer l'esthétique générale du prototype tout en protégeant les connexions contre d'éventuelles détériorations ou déconnexions accidentelles.

Ces éléments ont été conçus sur mesure afin de s'adapter aux dimensions de la maquette et au positionnement des différents capteurs. Les caches permettent ainsi de guider proprement le cheminement des câbles sous la structure du parking, tout en conservant un accès simple pour les opérations de maintenance ou de modification du câblage.

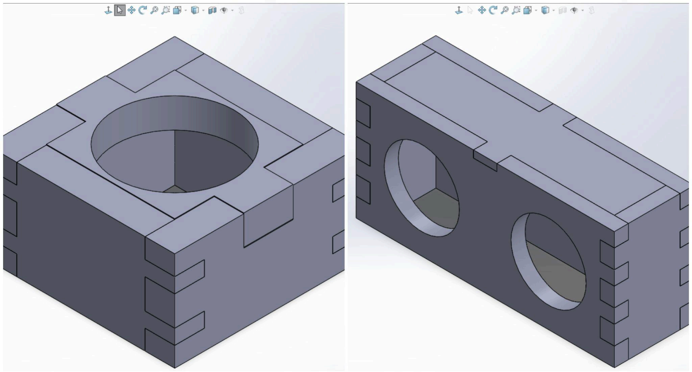
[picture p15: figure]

Figure 4.6.1 : Modélisation des caches des composants

V - TESTS ET RÉSULTATS

### 5.1 Objectifs des Tests

Une fois le développement de l'application web et de la maquette électronique terminé, plusieurs tests ont été réalisés afin de vérifier le bon fonctionnement de l'ensemble du système.

Ces tests avaient pour objectif de valider :

- le fonctionnement des capteurs de présence ;
- la communication entre les composants électroniques ;
- la lecture des QR codes ;
- l'ouverture automatique des barrières ;
- la synchronisation avec la base de données ;
- la mise à jour en temps réel des informations affichées sur le site web.

### 5.2 Environnement de Test

Afin de limiter les risques d'erreur lors du développement, plusieurs outils de simulation ont été utilisés avant l'implémentation sur le matériel réel.

Simulation électronique
La conception des circuits et la validation des branchements ont été réalisées à l'aide des plateformes de simulation électronique :
- TinkerCad
- Wokwi

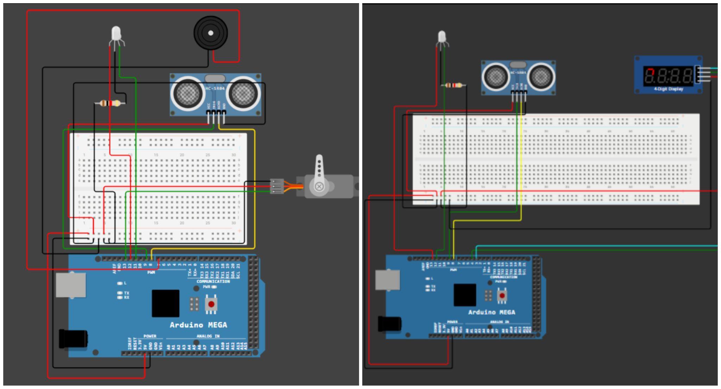
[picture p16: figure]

Figure 5.1 : Simulation des composants sur Wokwi

Ces outils ont permis de tester le comportement des composants sans nécessiter immédiatement le matériel physique.

Tests sur matériel réel
Après validation des simulations, les différents composants ont été assemblés sur la maquette afin de vérifier leur comportement dans des conditions proches d'une utilisation réelle.

Les essais ont porté sur :

- les capteurs ultrasoniques ;
- les LEDs de signalisation ;
- les servomoteurs ;
- l'écran LCD ;
- les modules ESP32-CAM ;
- la carte Arduino UNO R4 WiFi.

### 5.3 Tests Fonctionnels

Test de détection des véhicules
Ce test consiste à vérifier que les capteurs détectent correctement la présence d'un véhicule sur une place de stationnement.

Résultat obtenu :

- détection partiellement rapide ;
- changement immédiat de l'état de la place ;
- allumage de LED correspondante.

Le test a été considéré comme concluant

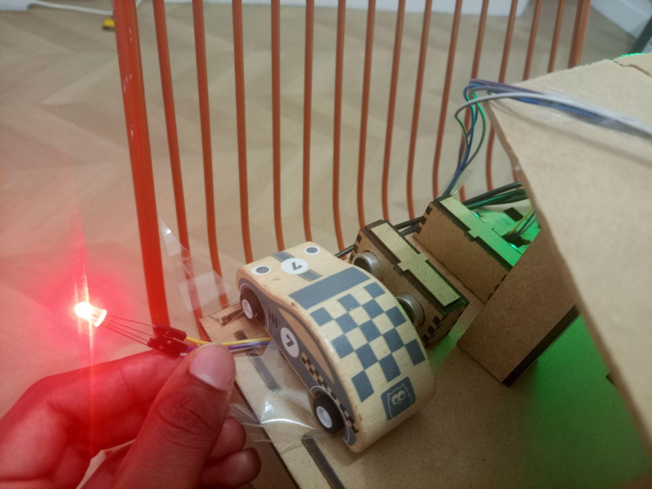
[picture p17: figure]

Figure 5.2 : Test de détection des places par les capteurs et allumage de la LED correspondante

Test de lecture des QR Codes

Différents QR codes valides et invalides ont été présentés devant l'ESP32-CAM afin de vérifier la fiabilité du système d'identification.

Résultat obtenu :

- reconnaissance correcte des QR codes valides ;
- refus automatique des codes invalides ;
- transmission des données vers le serveur.

Test d'ouverture de la barrière
Après validation du QR code, le servomoteur devait ouvrir automatiquement la barrière.

Résultat obtenu :

- ouverture instantanée après validation ;
- fermeture automatique après passage du véhicule ;
- aucun blocage observé durant les essais.

Test de synchronisation avec le site web
Chaque changement d'état d'une place devait être immédiatement visible sur l'application web.

Résultat obtenu :

- mise à jour correcte de la base de données ;
- actualisation de l'interface utilisateur ;
- cohérence entre l'état physique et l'état affiché.

### 5.4 Résultats Obtenus

Les différents tests réalisés ont permis de valider les principales fonctionnalités du système.

Réactivité
Le temps de réponse global du système s'est révélé satisfaisant. Les actions effectuées sur la maquette sont rapidement répercutées sur l'interface web.

Fiabilité
Les essais ont montré une bonne stabilité du système. Aucun dysfonctionnement majeur n'a été constaté durant les phases de test.

Détection
Les capteurs ont correctement identifié l'occupation des places de stationnement avec une précision suffisante pour le cadre du projet.

Communication Web ↔ Matériel
La communication entre l'Arduino, les modules ESP32 et le serveur Symfony a fonctionné conformément aux attentes. Les échanges de données ont permis d'assurer une synchronisation continue entre la maquette et la plateforme de gestion.

### 5.5 Analyse des Limites

Malgré les résultats obtenus, certaines limites ont été identifiées : (1) La précision des capteurs peut être influencée par la position des véhicules ou par certaines conditions environnementales ;(2) Le prototype a été développé à petite échelle et ne permet pas encore de représenter la gestion d'un parking de grande capacité ; (3) Enfin, la reconnaissance des QR codes dépend fortement de la qualité de l'éclairage et de la distance entre le code présenté et la caméra.

VI - CONCLUSION GÉNÉRALE ET PERSPECTIVES

Le projet DAVINCI CUSTOM GARAGE nous a permis de concevoir et de réaliser un prototype fonctionnel de stationnement intelligent associant développement web, systèmes embarqués et électronique. L'objectif principal était de proposer une solution capable de faciliter la gestion des places de stationnement tout en assurant une communication en temps réel entre une infrastructure physique et une plateforme numérique.

Au cours de ce projet, nous avons mis en œuvre de nombreuses compétences acquises durant notre formation en Bachelor Cybersécurité. La conception de l'application web sous Symfony, le développement de l'API de communication, la gestion de la base de données ainsi que la programmation des composants électroniques nous ont permis d'aborder concrètement les problématiques liées aux systèmes connectés.

Les résultats obtenus démontrent la faisabilité de la solution proposée. Le système est capable de détecter l'occupation des places de stationnement, de mettre à jour les informations en temps réel, de gérer les réservations via une interface web et de contrôler l'accès au parking grâce à un mécanisme de validation par QR code. Les différents tests réalisés ont confirmé le bon fonctionnement de l'ensemble des fonctionnalités développées.

Malgré ces résultats satisfaisants, certaines limites subsistent. Le prototype a été conçu à une échelle réduite et ne prend pas encore en compte l'ensemble des contraintes que pourrait rencontrer un déploiement réel, notamment en matière de gestion d'un grand nombre d'utilisateurs, de résistance aux conditions extérieures ou encore de disponibilité permanente du réseau.

Plusieurs pistes d'amélioration peuvent être envisagées pour faire évoluer le projet. L'intégration d'algorithmes d'intelligence artificielle pourrait permettre une meilleure prédiction de l'occupation du parking et une optimisation dynamique des emplacements disponibles. L'utilisation de technologies de reconnaissance automatique des plaques d'immatriculation pourrait également remplacer ou compléter le système de QR code. Une application mobile dédiée pourrait être développée afin de faciliter les réservations et la consultation des disponibilités en temps réel. Enfin, l'intégration de solutions cloud et de systèmes de paiement automatisés permettrait de rapprocher davantage le prototype d'une solution exploitable dans un environnement professionnel.

Ce projet constitue ainsi une première étape vers la conception d'infrastructures de stationnement intelligentes capables de répondre aux enjeux de mobilité urbaine de demain. Il nous a permis d'acquérir une expérience concrète de la gestion de projet, du travail en équipe et du développement de systèmes connectés, tout en mettant en pratique les connaissances techniques acquises au cours de notre formation.

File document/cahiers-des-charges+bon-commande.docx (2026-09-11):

REDACTION DU CAHIER DES CHARGES .

Intitulé du projet : DAVINCI CUSTOM GARAGE .

Numéro de l’équipe : 108

Date de rédaction : 30/11/2025

Membre de l’équipe :

NOMS | PRENOM
Siewe | Kyllian
Abdulrahman | El Najjar
Tiss | Adam
Vikash | Srikanthan

Table des matières

1 CAHIER DES CHARGES (CDC) 2

1.1 Contexte et présentation du projet 2

1.2 Besoins et contraintes. 3

1.3 Résultat attendu. 5

2 Analyse fonctionnelle. 5

2.1.1 Analyse du besoin. 5

2.1.2 Analyse fonctionnelle du besoin. 7

2.1.3 Cahier des charges fonctionnels. 8

2.1.4 Analyse fonctionnelle technique. 9

3 Analyse structurelle. 10

# 1 CAHIER DES CHARGES (CDC)

## 1.1 Contexte et présentation du projet

Contexte

Dans le cadre de notre cursus 2025-2026 en BACHELORS A1 CYBERSÉCURITÉ , nous réaliserons une étude succincte dans le domaine du stationnement intelligent intégrant des technologies numériques et électroniques pour assurer une gestion fluide, sécurisée et durable des espaces de stationnement . Notre projet s'inscrit dans le domaine de gestion dans lequel nous réaliserons une maquette représentant le fonctionnement d’un parking intelligent et les innovations potentielles.

En effet avec la croissance exponentielle des véhicules dans les grandes villes et métropoles ; dans des pays comme la Chine on présente plus de (https://www.transitionsenergies.com/combien-voitures-monde/)300millions (https://www.transitionsenergies.com/combien-voitures-monde/) de véhicules en circulation sur les routes chinoises. Ainsi, trouvé une place de parking est devenu un réel enjeu pour les automobilistes créant par la suite une obstruction fréquente des trafics et la multiplication des émissions de CO2 et des gaz à effet de serre : plus les conducteurs cherchent des parkings plus leur véhicule libère le CO2 constituant ainsi un réel danger environnemental pour la faune et la flore .

Les tous premiers systèmes de stationnement intelligents reposaient sur l’utilisation de la mécanique et des circuits entièrement manuel géré par un gardien tels le (https://youtu.be/s3CWjVrmDqk)Park-O-Mat (https://youtu.be/s3CWjVrmDqk), Ensuite sont apparues les applications mobiles avec les barrières automatiques comme l’illustre parfaitement (https://zenpark.com/comment)Zenpark (https://zenpark.com/comment) jusqu’à l’utilisation des robots valets autonome pour la gestion des véhicules comme le fait (https://stradot.com/)Stradot (https://stradot.com/) .

Les objectifs de notre projet seront de simplifier et moderniser l’utilisation de places de parkings dans les villes pour ainsi réduire le temps d’attente et d’une certaine manière relever l’économie des accréditant et accréditées (propriétaires de parkings inutilisés).

Présentation du projet

DAVINCI CUSTOM GARAGE ,

Pourrait être le futur du stationnement intelligent dans toutes les villes du monde entier. Face à cet accroissement de l’automobile les places de parking deviennent prisées et c’est dans cette logique que les parking connectés et intelligent voient alors le jour comme une innovation cruciale. On constate que beaucoup de personnes véhiculées sont contraints d’abandonner leurs véhicules dans des zones interdites ou non sécurisée à cause d’un « manque de place de parking » bien qu’ils existent de nombreux espaces de parking publiques ou privées et inexploitées à cause du simple fait que ces usagers ne possèdent pas « l’information » .

Notre projet combinera les technologies et méthodologies informatiques notamment la (https://www.rocq.inria.fr/secret/Anne.Canteaut/COURS_C/cours.pdf)programmation (https://www.rocq.inria.fr/secret/Anne.Canteaut/COURS_C/cours.pdf) , systèmes embarqué et l’électronique avec l’utilisations des cartes programmables (Arduino) (https://perso-laris.univ-angers.fr/~cottenceau/ArduinoCottenceau2016.pdf) et des microcontrôleurs (ATMega328 (https://datasheet.octopart.com/ATMEGA328-AU-Microchip-datasheet-65729177.pdf)) pour fluidifier l’accès au parking .

Comme bien décrit dans notre état de l’art , notre projet mettra en relation les utilisateurs avec les parkings à travers une interface Web(User) bien définie dans laquelle les places disponibles seront consignées à des tarifs préférentiels . Nous, propriétaires de la plateforme auront accès à une interface Admin ou Back ou nous auront toutes les données concernant les réservations et les clients . Tout ceci sera brièvement manipulé à l’aide de (https://symfony.com/doc/current/setup.html)Symfony (https://symfony.com/doc/current/setup.html) qui mettra en relation les doctrines(bases de données), le traitement avec le (https://dev.mysql.com/)SQL (https://dev.mysql.com/) et l’affichage avec le Html.

Au niveau du prototypage notre garage sera entièrement manipulé par l’Arduino et son IDE pour l’automatisation de certaines tâches . En effet , après réservation sur la page Web , sera transmis un code unique à l’usager pour son entrée dans le garage ; changeant ainsi des tickets de garage en carton qui polluent nos rues . Ce code entré sur un clavier analogique permettra d’actionner l’ouverture des barrières automatiques pour laisser entrer la voiture qui sera par la suite conduite automatiquement sur la place de parking réservée par des tapis roulants (si possible) . Et enfin une fois sur sa place une (https://www.tme.eu/Document/e17ac5a5d91f1e843e5681cfa4a5ba4b/HLMP-HG64-VY0DD.pdf)LED (https://www.tme.eu/Document/e17ac5a5d91f1e843e5681cfa4a5ba4b/HLMP-HG64-VY0DD.pdf) s’allumera signifiant que le parking est occupé et un tableau de bord pour un message de bienvenue.

Etant donnée que ce projet dans est à but éducatif les données personnelles entrées(code bancaire , nom , code compte etc.) seront entièrement générés par des (https://fakerphp.org/)Fakers (https://fakerphp.org/) (des données tests) .

## 1.2 Besoins et contraintes

Dans le cadre de la réalisation d’un projet , il est très important de mettre en relief les potentiels besoins des futurs usagers afin d’en déduire des solutions adéquates en tenant compte des restrictions ou contraintes et exigences .

Besoin

· Quels sont les besoins fonctionnels ?

-Trouver rapidement une place de parking :

Notre Smart Parking doit permettre de trouver en un temps réduit des places disponibles pour un utilisateur et éviter ainsi les embouteillages dû à l’obstruction de la route par le véhicule en attente .

-Avoir l’état du parking en temps réel (informations) :

L’interface Web proposée aux utilisateurs doit renseigner le conducteur sur la disponibilité des places de parking ( occupées ou pas ) et sur les informations relatives à une réservation (coût , durée etc.) .

-Détecter automatiquement l’occupation des places.

Notre dispositif sera équipé de de matériels électroniques garantissant une détection autonome et continue des places de parkings afin d’éviter les confusions ou les réservations inutiles .

-Fiabilité ; la précision et la rapidité

Notre système devra fonctionner correctement dans toutes les conditions d’usage et également être précis dans sa détection afin d’éviter des erreurs ou des bugs de systèmes et ainsi offrir une réponse rapide pour assurer une mise à jour instantanée des informations affichées .

Contraintes

· Quelles sont les contraintes de ce projet ?

-Contraintes économiques :

*Budget limitée

Le projet doit être réalisé en respectant un budget restreint ( <= 150£) , ce qui impose de sélectionner des composants simples, efficaces. Il est donc nécessaire de privilégier des solutions économiques tout en conservant un bon niveau de qualité et de fiabilité .Les capteurs, afficheurs et modules électroniques doivent donc être choisis pour leur faible consommation, ce qui contribue aussi à la durabilité du système.

-Contraintes environnementales :

Les contraintes environnementales imposent de concevoir un smart parking éco-responsable, en limitant la consommation énergétique des capteurs, de l’éclairage et des systèmes de communication .Les composants et matériaux employés dans la conception du parking intelligent doivent être respectueux de l’environnement. Il est nécessaire de privilégier des éléments recyclables, durables ou ayant un faible impact écologique.

-Contraintes matériels :

Les contraintes matérielles concernent la robustesse et la fiabilité des équipements utilisés dans le parking intelligent. Les capteurs, bornes et panneaux doivent résister aux intempéries, aux variations de température et aux chocs. Les éléments du système (capteurs, câbles, panneaux d’affichage…) doivent être installés de manière à ne pas perturber la circulation dans le parking. Ils doivent aussi être positionnés de façon à ne pas réduire la visibilité des conducteurs .

-Contraintes juridiques :

Le smart parking doit respecter le RGPD(Règlement Général sur la Protection des Données) et les recommandations CNIL(Commission Nationale de l’Informatique et des Libertés) pour le traitement des données (caméras, plaques, application). Les installations doivent suivre les normes électriques et de sécurité. Le parking doit être conforme aux règles d’accessibilité, au code de la route pour la signalisation interne, et aux obligations juridiques liées aux contrats, paiements et responsabilités. Enfin, toute installation physique doit être autorisée par la mairie .

-Contraintes de la faisabilité :

Les contraintes de faisabilité déterminent si le smart parking peut être réalisé dans les conditions techniques, humaines et temporelles du projet. Elles imposent d’abord de vérifier la disponibilité des ressources nécessaires : compétences en programmation, électronique, réseau, ainsi que l’accès au matériel requis (capteurs, microcontrôleurs, serveurs, alimentation) .

## 1.3 Résultat attendu

àMaquette et SolidWorks

# 2 Analyse fonctionnelle

### 2.1.1 Analyse du besoin

· Pourquoi ce besoin existe -il ?

L’origine de ce problème est la suivante : le nombre de véhicules en France ne cesse d’augmenter au fil des années . On compte près de (https://www.vie-publique.fr/en-bref/300231-les-chiffres-cles-du-parc-automobile-en-france-en-2025)39,7 millions (https://www.vie-publique.fr/en-bref/300231-les-chiffres-cles-du-parc-automobile-en-france-en-2025) de voitures sur les routes françaises soit une hausse de 1% en un an . Cet allongement du parc des véhicules est dû à l'allongement des durées de vie des véhicules qui crée ainsi un manque cruel de places de parking .(Source : Vie publique ).

· Pourquoi le produit existe -il ?

Ce parking intelligent va remédier au problème de perte de temps lors de la recherche des places de parking et optimiser sa gestion en temps réel et en parallèle la réduction de la pollution.

· Qui sont les principaux concernés ?

Les personnes ou acteurs les plus affectés par ce problème de stationnement sont les usagers réguliers de la route , notamment les chauffeurs de (https://serres.ifsttar.fr/fileadmin/contributeurs/serres/Action5/5-12_CETE69_ERA12_Rapport_Biblio_SERRES_V01.pdf)gros porteurs (https://serres.ifsttar.fr/fileadmin/contributeurs/serres/Action5/5-12_CETE69_ERA12_Rapport_Biblio_SERRES_V01.pdf) , et les conducteurs de voitures et taxis.

· Que recherchent vraiment les automobilistes ?

Une application qui leur permet d’avoir connaissance de façon fluide (simplicité de la plateforme) en temps réel des places de parkings disponibles, sécurisées et accessibles en tout temps .

· Quelle est la matière d’œuvre ?

Ce projet va principalement s’appliquer sur les voitures et les parkings .

· Quand pourra-t-on dire que le besoin est répondu ?

Lorsque le parking intelligent facilite réellement le stationnement, améliore la circulation et fournit des informations fiables aux utilisateurs.

Bête à corne

La Bête à cornes est un outil graphique d’analyse fonctionnelle qui permet de définir clairement et simplement le besoin fondamental d’un projet avant de concevoir une solution. Il répond à trois questions essentielles : *Pour qui le système est-il utile ? *Sur quoi agit-il ? et *Dans quel but existe-t-il ? . Il sert donc de base solide pour orienter la conception du projet, et garantir que la solution finale répondra réellement aux attentes exprimées.

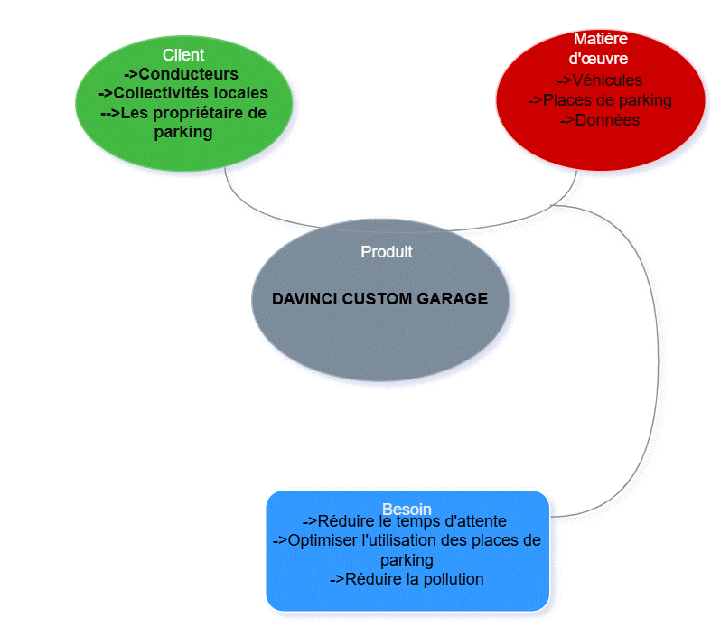
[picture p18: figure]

Explication du diagramme :

Notre projet consiste à concevoir un parking intelligent pour pallier le problème de stationnement et de recherche de places de parking par les conducteurs , les collectivités locales et les propriétaires de parking . Il agit sur les véhicules en général (gros et petits porteurs) et les places de parkings . Ses fonctions principales seront de réduire le temps de recherche et la pollution et d'optimiser la gestion des places de parkings .

### 2.1.2 Analyse fonctionnelle du besoin

Il est important lors de la réalisation d’un projet au but collectif , d’identifier et de recenser toutes les fonctions probables afin de cerner le réel problème de l’utilisateur et de trouver des solutions techniques adéquates et réalisables . Pour mener à bien cette recherche nous allons passer par la réalisation d’un « diagramme pieuvre » ; qui met en relation le projet avec les éléments du milieu extérieur associé à leur fonctions respectives .

Diagramme Pieuvre

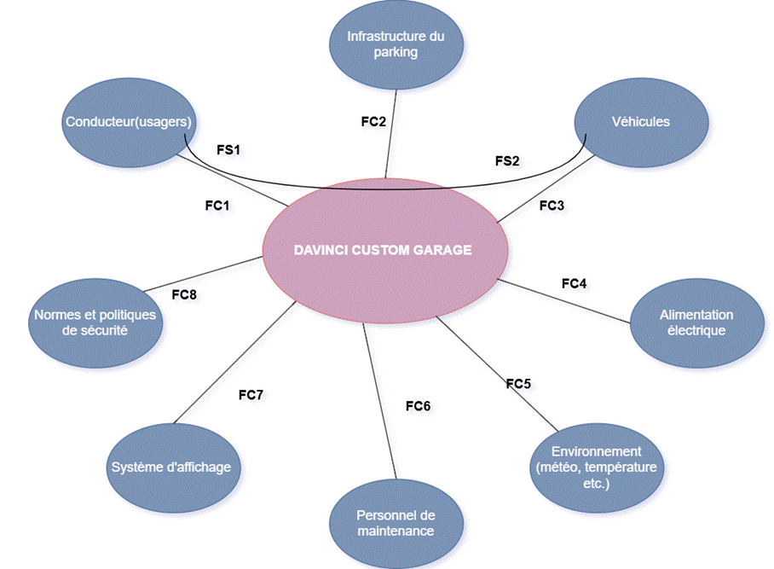
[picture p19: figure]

Description des fonctions du diagramme pieuvre :

1. Usagers (Conducteurs)

- FS/C1 : Guider l’utilisateur vers une place libre
- FS/C1 : Informer sur l’état du parking

2. Véhicules

- FS2/C3 : Détecter la présence ou l’absence d’un véhicule
- FS2/C3 : Mettre à jour en temps réel l’occupation des places

3. Infrastructure du parking

- FC2 : S’adapter à la configuration existante (murs, rampes, colonnes)
- FC2 : Ne pas gêner la circulation ni la visibilité

4. Alimentation électrique

- FC4: Consommer peu d’énergie

· FC4 : Assurer un fonctionnement continu et stable

5. Environnement (météo, température, poussière, luminosité)

- FC5: Résister aux conditions extérieures
- FC5 : Fonctionner correctement malgré les variations climatiques

6. Techniciens / Personnel de maintenance

- FC6 : Permettre une installation simple
- FC6 : Faciliter l’entretien et la réparation

7. Système d’affichage / Panneaux

- FP7 : Afficher les informations de disponibilité
- FC7 : Être visible et compréhensible pour tous

8. Normes et politiques de sécurité

- FC8 : Respecter les normes de sécurité électrique
- FC8 : Assurer la sécurité des usagers et éviter les risques

*Diagramme SADT

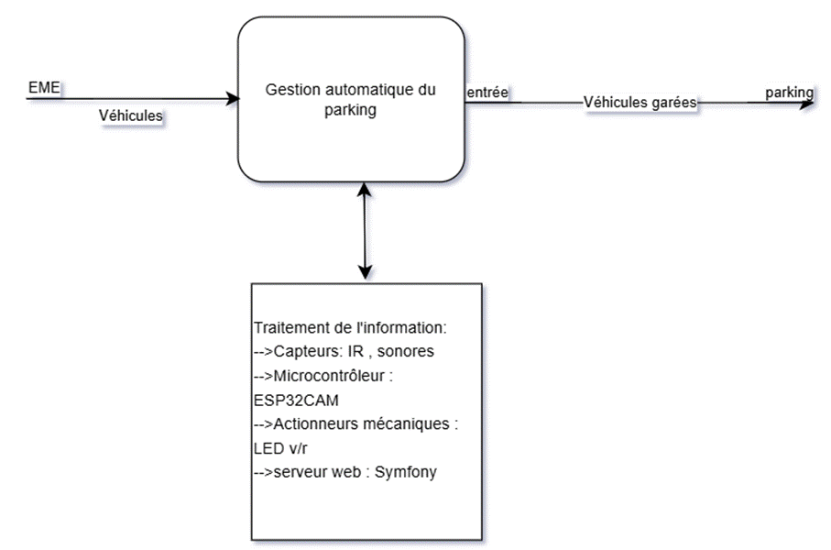
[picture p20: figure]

### 2.1.3 Cahier des charges fonctionnels

Dans cette étape de nous regroupons toutes les informations des étapes précédentes pour présenter clairement les fonctions du système . Il est question de classer et hiérarchiser les EME(éléments du milieu extérieur) et son interaction avec le système . Au terme de cette étape nous pourrons alors estimer les coûts et prendre les décisions finales pour le développement du projet .

Caractérisation des EME

ÈME | Interaction avec le système
Conducteurs | Consulter les informations et se garer rapidement
Véhicules | Être détectés par les capteurs pour mettre à jour l’occupation
Techniciens | Installer, contrôler et réparer le système
Alimentation électrique | Fournir l’énergie nécessaire au fonctionnement continu
Infrastructure | Accueillir les capteurs, panneaux et circulation sans gêner
Système d’affichage | Afficher l’état des places libres pour guider les usagers
Environnement | Influence la précision et la fiabilité des capteurs
Politiques de sécurité | Garantir la sécurité et la conformité légale du parking

Caractérisation des fonctions de services

Fonctions de services | Priorités
FP1 : Détecter automatiquement la présence des véhicules | élevée
FP2 : Informer les usagers sur les places disponibles | élevée
FP3 : Guider les usagers vers une place libre | Moyenne
FP4 : Sécuriser la circulation dans le parking | élevée
FP5 : Fonctionner en continu et de manière fiable | élevée
FP6 : Consommer peu d’énergie | élevée
FP7 : Permettre une maintenance simple | Moyenne

### 2.1.4 Analyse fonctionnelle technique

Cette partie de notre devoir va nous permettre de transformer les besoins des usagers et du système en solutions techniques réalisables . Pour ce faire nous allons passer par la matérialisation d’un diagramme FAST qui va nous permettre de représenter logiquement chaque fonction de service afin de mieux concevoir le projet .

Diagramme FAST

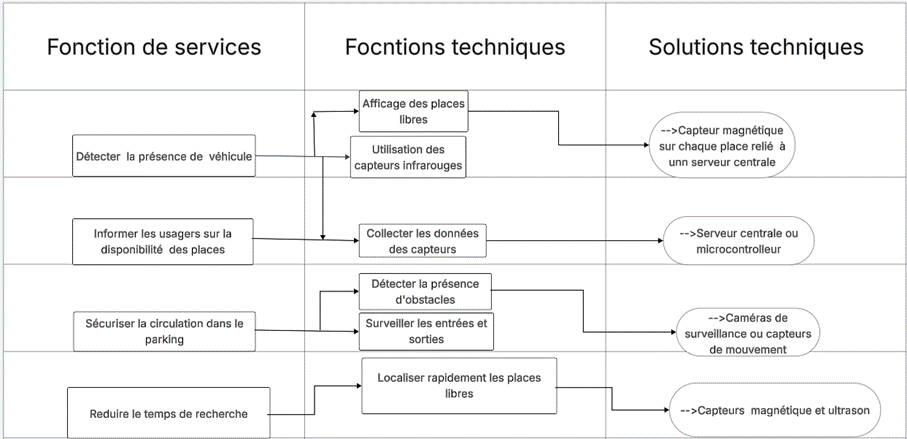
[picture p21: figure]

# 3 Moyen de communication

Pour mener à bien un projet d’équipe il est important de savoir communiquer entre collègues et les responsables (enseignants) pour une bonne cohésion des idées et des prises de décision favorables à tous . Dans notre équipe , nous sommes passé par l’utilisation de nombreuses plateformes de collaboration notamment :

Discord (https://discord.com/servers) (https://discord.com/servers): qui possède une messagerie en ligne et permet également d’effectuer des appels de groupe pour les débats et « brainstorming » important qui arrivé à la convergence de nos idées distinctes .

Google Docs (https://workspace.google.com/intl/fr/products/docs/) (https://workspace.google.com/intl/fr/products/docs/): dans lequel il est possible de rédiger un document en ligne et de façon simultanée avec d’autres personnes permettant ainsi de facilement venir en aide à un membre du groupe en difficulté.

Teams (https://teams.live.com/free): Qui nous a permis de contacter les enseignants en cas d’incompréhension de la matière .

.Planning prévisionnel

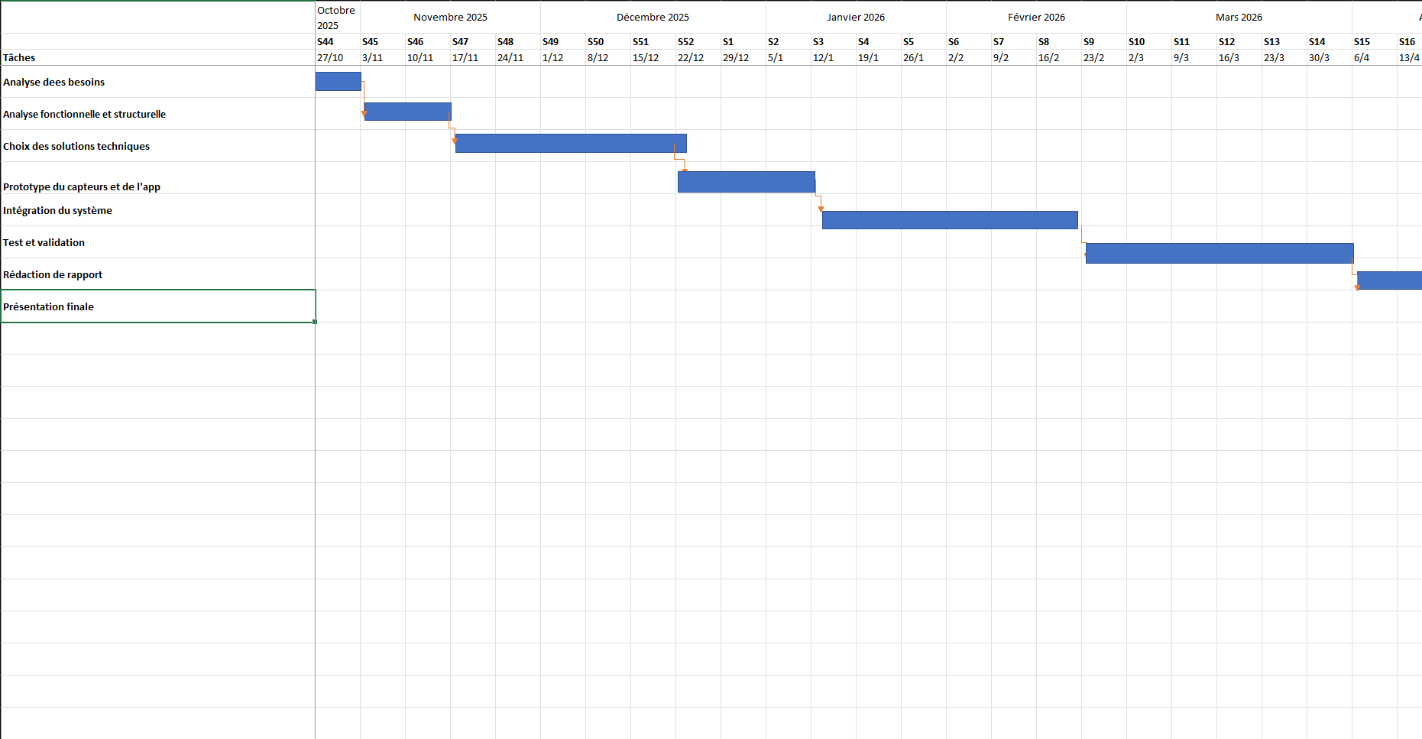
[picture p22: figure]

# 4 Analyse structurelle

Contrairement à l’analyse fonctionnelle qui elle décompose le système en plusieurs fonctions , l’analyse structurelle quant à elle décompose ce dernier en sous-systèmes, modules, composants puis décrit leur relation , rôle et interaction . En d’autres termes après cette partie on verra comment les différentes parties du système collaborent pour atteindre les fonctions attendues .

## 4.1 Composition du système et Organisation hiérarchique

Cette étape va nous permettre de décomposer notre système en sous-systèmes et les composants nécessaires pour leur fonctionnement.

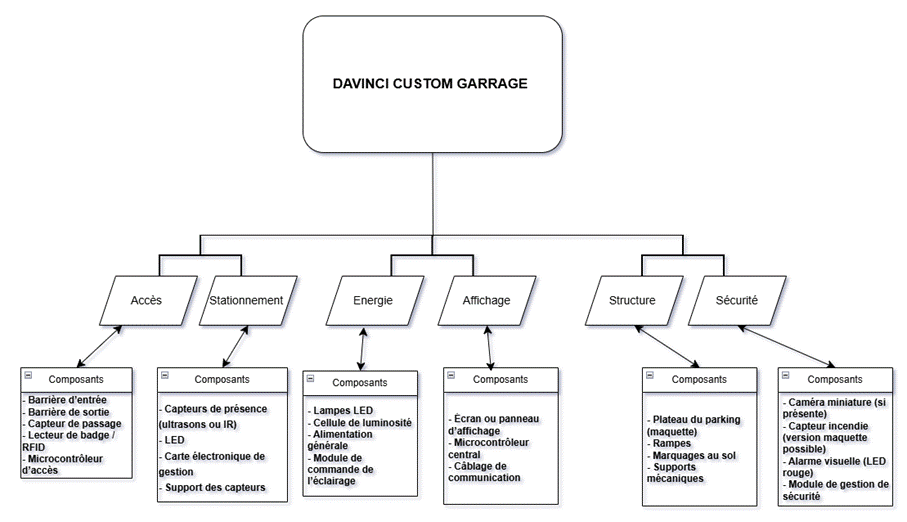
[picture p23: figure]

## 4.2 Interface et liaison

Cette partie de notre devoir va recenser toutes les interfaces qui existent dans notre système et les liaisons entre ces composants .

Interface 1 : Capteurs de présence + Microcontrôleur

*Type de liaison : électrique + analogique

*Fonction : transmettre la détection de véhicule pour gérer les places.

Interface 2 : Barrière automatique + Microcontrôleur

*Type de liaison : électrique

*Fonction : permettre l’ouverture et la fermeture de la barrière selon les autorisations.

Interface 3 : Microcontrôleur + Écran / Afficheur

*Type de liaison : analogique

*Fonction : afficher le nombre de places disponibles ou un message.

Interface 4 : Capteur de passage + Barrière

*Type de liaison : analogique

*Fonction : déclencher automatiquement la fermeture après le passage d’un véhicule.

Interface 5 : Alimentation + Tous les modules

*Type de liaison : électrique

*Fonction : assurer la fourniture d’énergie à l’ensemble du système.

Interface 6 : Structure mécanique + Capteurs

*Type de liaison : mécanique

*Fonction : maintenir en position les éléments du système.

## 4.3 Flux

Les différents types de flux que l’on rencontrera dans sont principalement les :

*les flux d’informations analogiques : entre les capteurs et les actionneurs et les microcontrôleurs car ils ne fonctionnent qu’en signal analogique .

*les flux d’énergie électrique : entre tous les composants électroniques du circuit

*Les flux mécaniques : qui sont les mouvements physiques effectués entre les composants du circuit . (ex : levée et descente de la barrière)

## 4.4 Organisation spatiale

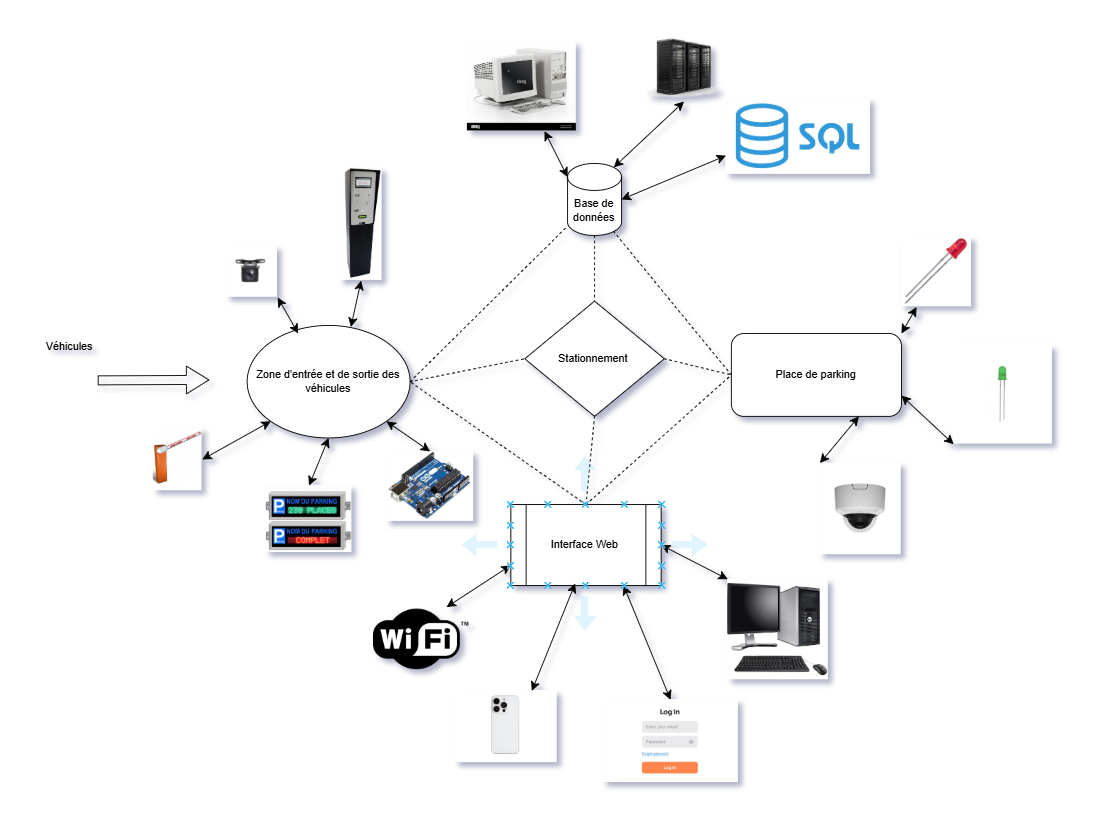
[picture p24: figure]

## 4.5 Bon de commande

Matériels | Quantité | Prix Unitaire (TTC) | Fournisseur | Rôle
Carte Arduino Mega 2560 R3 (Compatible) | 1 | 45.60 € | GoTronic (https://www.gotronic.fr/art-arduino-mega-2560-a000067-12421.htm) | Micro contrôleur principal. Il traite les données des capteurs et contrôle les actionneurs.
Module ESP32-CAM | 1 | 14.30 € | GoTronic (https://www.gotronic.fr/art-module-esp32-cam-32630.html) | Lecture de la plaque d’immatriculation et détection de la place de parking libre
Capteur de distance Ultrason HC-SR04 | 6 | 3,84 € | Lextronic (https://www.lextronic.fr/capteur-a-ultrasons-hc-sr05-40424.html?f) | Détecter si une voiture est sur une place
Module détecteur d'obstacle Infrarouge (IR) | 2 | 2,99 € | Atelier de la Robotique (https://www.atelierdelarobotique.fr/produit/capteur-infrarouge-pour-arduino) | Détecter une voiture à l’entré et la sortie du parking
Bouton poussoir 2 Pins | 3 | 0,60 € | Lextronic (https://www.lextronic.fr/bouton-poussoir-miniature-6x6x5-mm-a-2-broches-76440.html?fast_search=fs) | Ouvrir la barrière de manière manuelle (2 de secours car le bouton est fragile)
Micro-Servomoteur FT90B | 1 | 4,95 € | Lextronic (https://www.lextronic.fr/mini-servomoteur-feetech-ft90b-faible-tension-77915.html) | Permet d’ouvrir et fermer la barrière du parking
LEDs 4 Pins (RDG) | 6 | 0,65 € | GoTronic (https://www.gotronic.fr/art-led-rgb-5-mm-rgb5-dif-2099.htm) | Indiquer si une place est occupé ou non
Adaptateur GROVE 3 Pins Mâle | 1 | 3,40 | Lextronic (https://www.lextronic.fr/adaptateurs-grove-vers-3-broches-males-60584.html) | Adaptateur pour brancher le ruban led sur la Breadboard
Ecran LCD 2x16 caractères LCD16X2I2C | 1 | 8,50 € | GoTronic (https://www.gotronic.fr/art-afficheur-lcd-2x16-caracteres-lcd16x2i2c-25650.htm) | Afficher les places libres dans le parking
Breadboard(830 points) | 1 | 5,90 € | Lextronic (https://www.lextronic.fr/plaque-de-connexion-sans-soudure-830-contacts-63982.html?fast_search=fs) | Connecter les composant à l'Arduino
Lot de 40 Câbles Dupont mâle-femelle | 1 | 3,99€ | Atelier de la Robotique (https://www.atelierdelarobotique.fr/produit/cables-dupont-male-femelle-de-10cm-20cm-30cm-pour-arduino) | Connecter les différents capteurs à la carte Arduino
Lot de 40 Câbles Dupont femelle-femelle | 1 | 3,99€ | Atelier de la Robotique (https://www.atelierdelarobotique.fr/produit/cables-dupont-femelle-femelle-de-10cm-20cm-30cm-pour-arduino) | Connecter les différents capteurs à la carte Arduino
Lot de 40 Câbles Dupont mâle-mâle | 1 | 3,99€ | Atelier de la Robotique (https://www.atelierdelarobotique.fr/produit/cables-dupont-male-male-de-10cm-20cm-30cm-pour-arduino) | Connecter les différents capteurs à la carte Arduino
Ruban Led RVB 1M | 1 | 13,40€ | Lextronic (https://www.lextronic.fr/grove-ruban-60-leds-rvb-ws2813-40879.html) | Éclairer le parking
TOTAL TTC : | | 142,74€

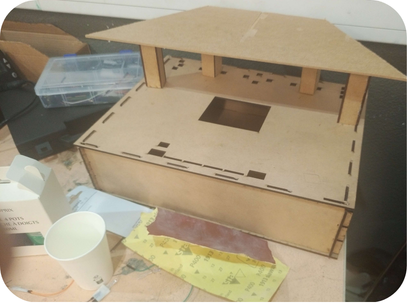
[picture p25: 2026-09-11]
images/image-prototype.png

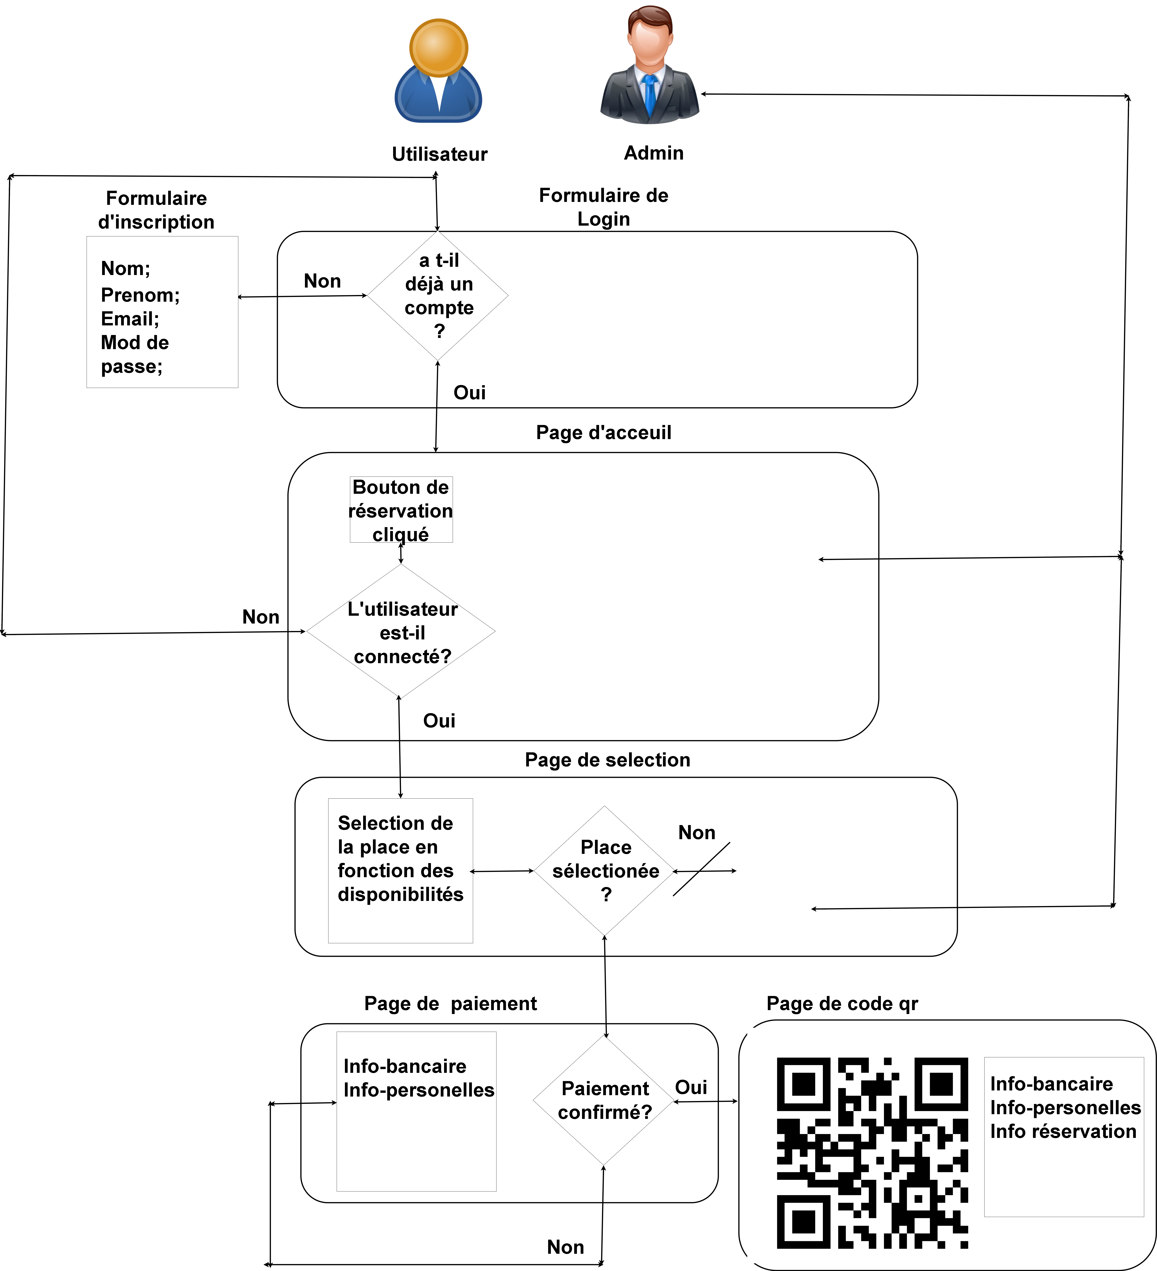
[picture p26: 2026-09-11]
document/User-Path-Tracking.drawio.png

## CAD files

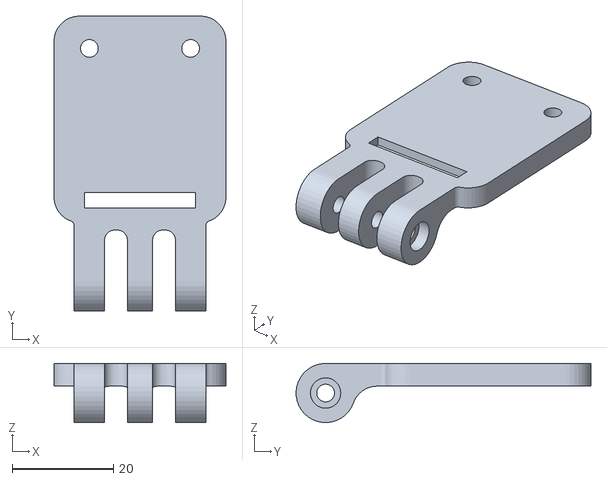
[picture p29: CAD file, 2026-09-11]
3d-modeling/ArduCam/Arducam OV2640 SPI Back3-5.STL
34.0 x 58.3 x 11.7

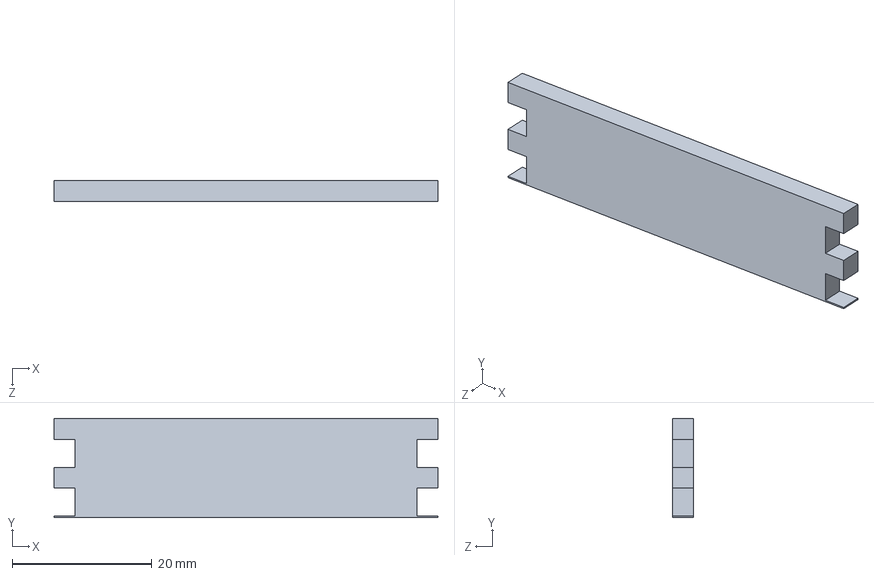
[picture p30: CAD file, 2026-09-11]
3d-modeling/Autres/Mur-longueur-Support.SLDPRT
55.0 x 14.2 x 3.00 mm

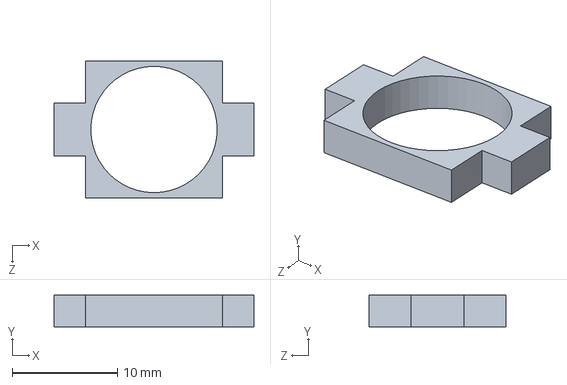
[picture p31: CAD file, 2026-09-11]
3d-modeling/Buzzer/Surface-Buzzer.SLDPRT
19.0 x 3.00 x 13.0 mm

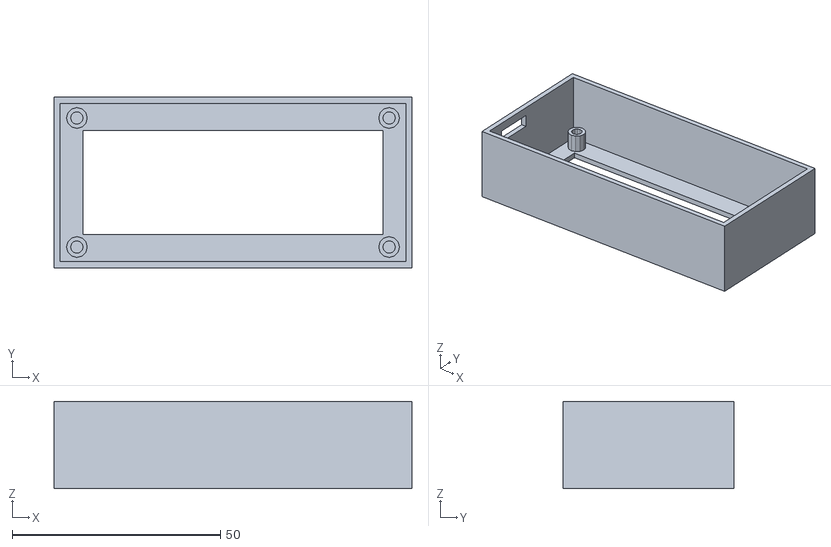
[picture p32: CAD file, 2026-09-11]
3d-modeling/LCD-Screen/Digispark_LCD_flat.stl
86.0 x 41.0 x 21.0

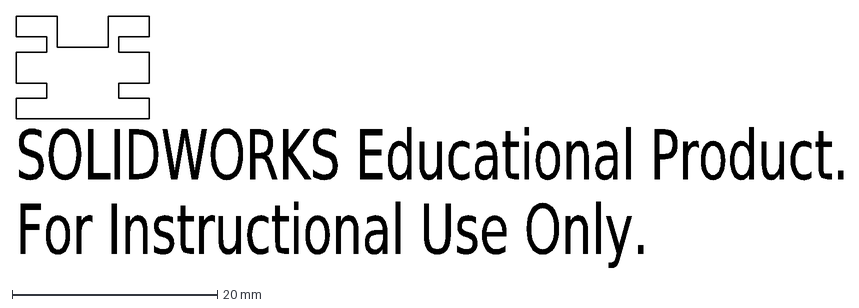
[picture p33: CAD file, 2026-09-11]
3d-modeling/Pièces-Supplémentaires/Mur-longueur-Bouton.DXF
SOLIDWORKS Educational Product.
For Instructional Use Only.

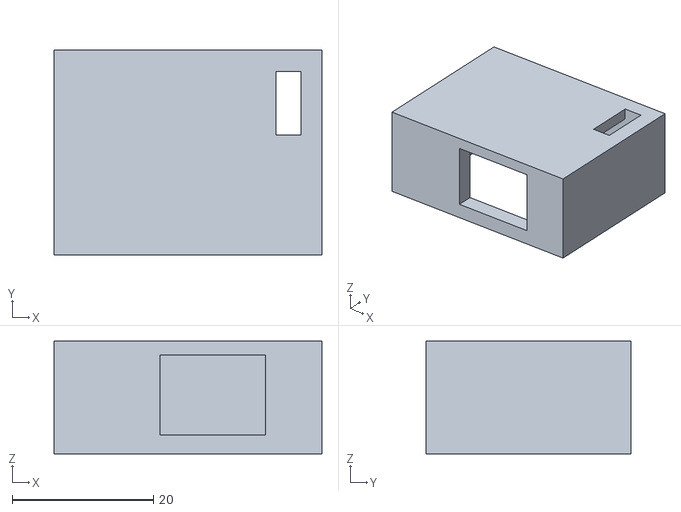
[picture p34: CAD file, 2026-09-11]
3d-modeling/ServoMoteur/cache moteur.STL
38.0 x 29.0 x 16.0

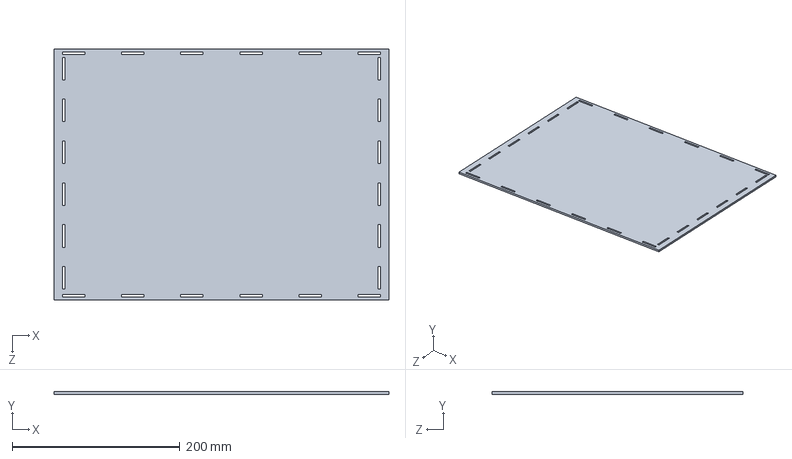
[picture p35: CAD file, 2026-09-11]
3d-modeling/Support/Sol-Sous-Sol.SLDPRT
400.0 x 3.00 x 300.0 mm

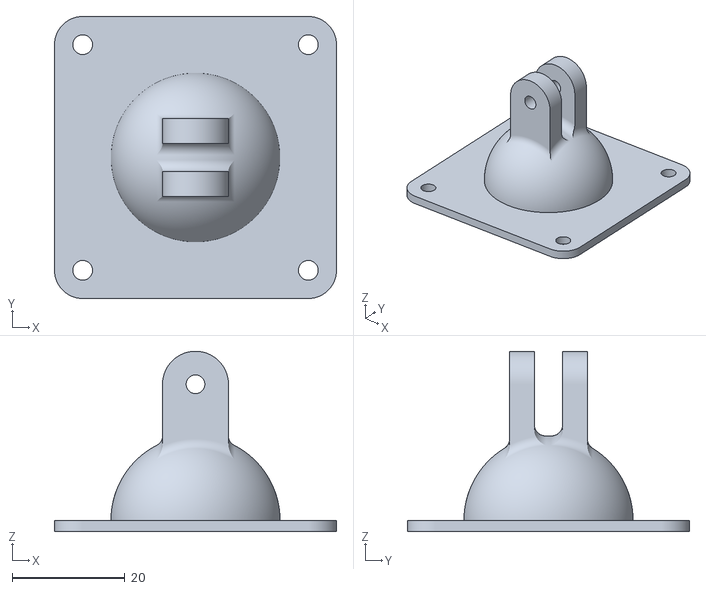
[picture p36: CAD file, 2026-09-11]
3d-modeling/ArduCam/Arducam OV2640 SPI Base.STL
50.0 x 50.0 x 32.0

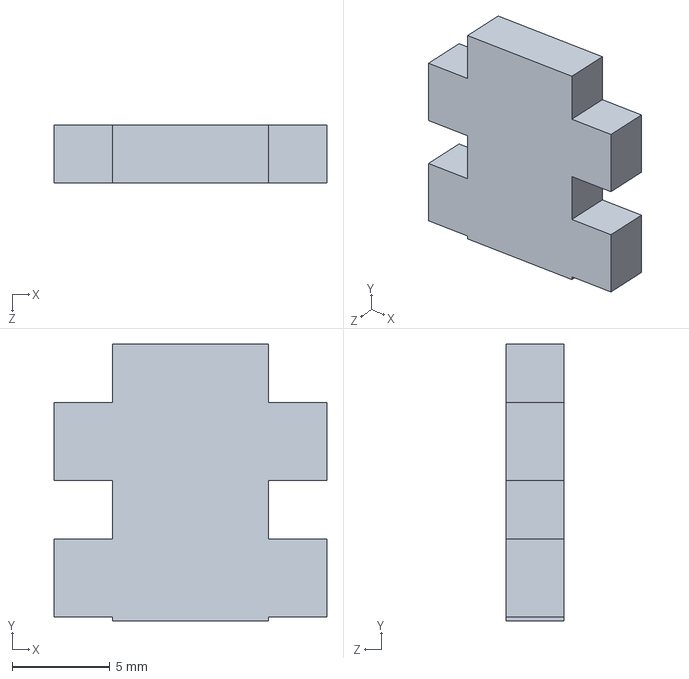
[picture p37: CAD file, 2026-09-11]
3d-modeling/Autres/Mur-Largeur-Support.SLDPRT
14.0 x 14.2 x 3.00 mm

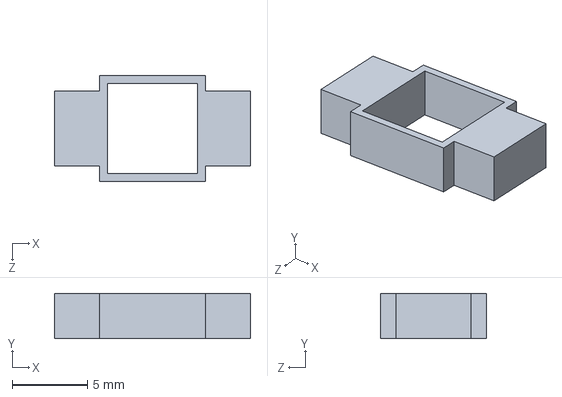
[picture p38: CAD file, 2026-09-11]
3d-modeling/Bouton/Surface-Bouton.SLDPRT
13.0 x 3.00 x 7.00 mm

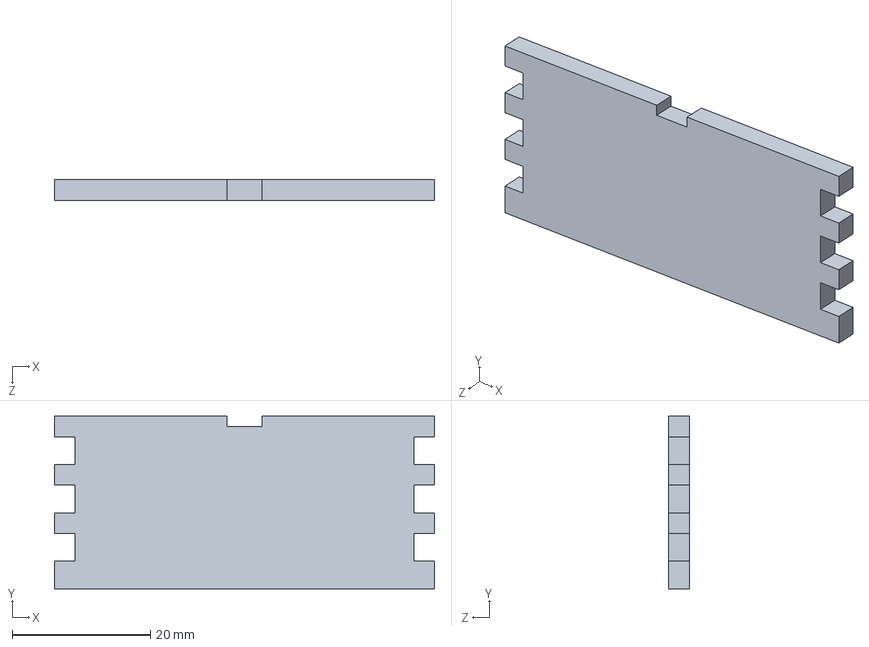
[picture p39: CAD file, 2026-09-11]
3d-modeling/HC-SR04/Mur-Longueur-HC-SR04.SLDPRT
55.0 x 25.0 x 3.00 mm

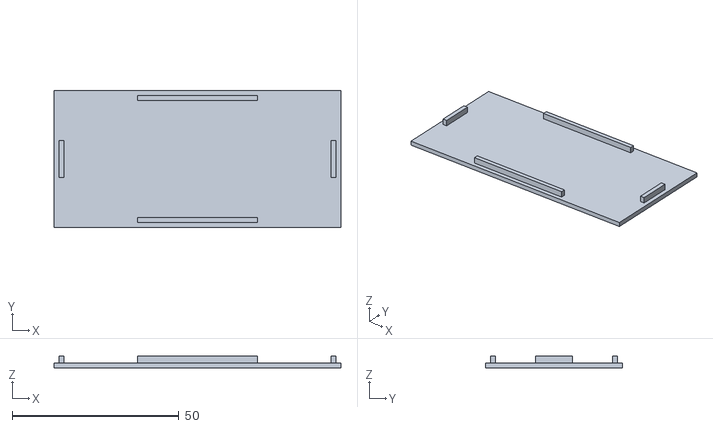
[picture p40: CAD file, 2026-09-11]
3d-modeling/LCD-Screen/Digispark_LCD_flat_bottom.stl
86.0 x 41.0 x 3.50

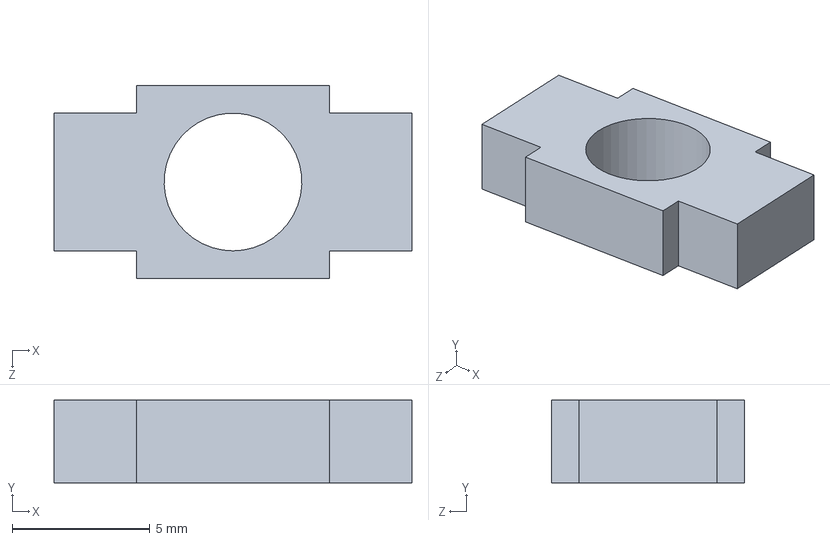
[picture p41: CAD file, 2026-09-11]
3d-modeling/LED/Surface-LED.SLDPRT
13.0 x 3.00 x 7.00 mm

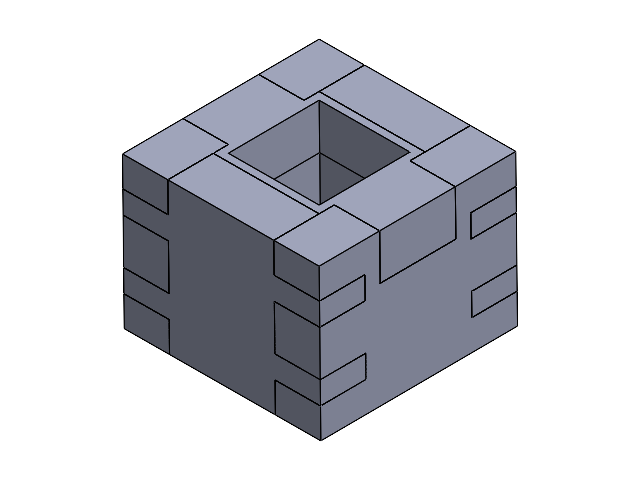
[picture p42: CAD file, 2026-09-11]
3d-modeling/Bouton/Assem-Bouton.SLDASM
Mur-largeur-Bouton x 2
Mur-longueur-Bouton x 2
Surface-Bouton

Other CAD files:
3d-modeling/HC-SR04/Assem-HC-SR04.SLDASM
3d-modeling/LED/Assem-LED.SLDASM
3d-modeling/Buzzer/Assem-Buzz.SLDASM
3d-modeling/Autres/Assem1.SLDASM
3d-modeling/ArduCam/Arducam OV2640 SPI Front.STL
3d-modeling/Bouton/Mur-largeur-Bouton.SLDPRT
3d-modeling/Bouton/Mur-longueur-Bouton.SLDPRT
3d-modeling/Buzzer/Mur-largeur-Buzzer.SLDPRT
3d-modeling/Buzzer/Mur-longueur-Buzzer.SLDPRT
3d-modeling/HC-SR04/Face-ultrason.SLDPRT
3d-modeling/HC-SR04/Mur-Largeur-HC-SR04.SLDPRT
3d-modeling/HC-SR04/couvert-HC-SR04.SLDPRT
3d-modeling/LED/Mur-largeur-LED.SLDPRT
3d-modeling/LED/Mur-longueur-LED.SLDPRT
3d-modeling/Pièces-Supplémentaires/Mur-Largeur-Support.DXF
3d-modeling/Pièces-Supplémentaires/Mur-largeur-Bouton.DXF
3d-modeling/Pièces-Supplémentaires/Mur-largeur-Buzzer.DXF
3d-modeling/Pièces-Supplémentaires/Mur-largeur-LED.DXF
3d-modeling/Pièces-Supplémentaires/Mur-longueur-Buzzer.DXF
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

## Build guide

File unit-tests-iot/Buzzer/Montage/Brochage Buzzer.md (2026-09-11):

Brochage Buzzer 

Carte : Arduino R4 Wifi 

**Vcc** : 13 

**GND** : GND

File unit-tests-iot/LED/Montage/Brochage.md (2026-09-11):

Brochage LED 

**Carte** : Arduino UNO R4 Wifi

**Vcc** --> Pin digitale (0 ou 1) ou analogique (0 à 255)

**GND** --> GND de la carte

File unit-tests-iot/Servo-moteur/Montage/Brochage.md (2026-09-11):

Brochage Servo  

**Carte** : Arduino R4 Wifi 

**VCC -->** 5V ou Vin 

**GND** --> GND de la carte 

**Data** (fil orange) --> Pin 9

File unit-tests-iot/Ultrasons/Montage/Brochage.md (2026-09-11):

Brochage HC-SR-04

**carte** : Arduino R4 Wifi 

**Vcc** --> Vin ou  5V

**GND** --> GND de la carte 

**echo** --> entre 13 et 12 (Digital pin)

**trigger** --> entre 13 et 12 (Digital pin)

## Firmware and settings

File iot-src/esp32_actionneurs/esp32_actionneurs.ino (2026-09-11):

/*
 * ============================================================
 *  ESP32 Nouvelle — Actionneurs Parking
 *  VERSION STABLE
 *
 *  Rôle : Serveur HTTP qui reçoit les commandes de l'Arduino
 *         et contrôle les servos, LEDs RGB et buzzers
 *
 *  Réseau : Se connecte au réseau "ParkingCam" (ESP32 existante)
 *  IP     : 192.168.4.3 (fixe)
 *
 *  Routes disponibles :
 *    POST /servo-open   → {"servo": "entree"} ou {"servo": "sortie"}
 *    POST /servo-close  → {"servo": "entree"} ou {"servo": "sortie"}
 *    POST /led          → {"place": 1, "color": "red"|"green"|"yellow"|"off"}
 *    POST /buzzer       → {"id": 1, "duration": 500}
 *    GET  /status       → état du système
 *    GET  /test         → vérification serveur
 *
 *  Branchements :
 *    Servo entrée       → GPIO 12
 *    Servo sortie       → GPIO 13
 *    LED Place 1 R/G    → GPIO 18 / 19
 *    LED Place 2 R/G    → GPIO 22 / 23
 *    LED Place 3 R/G    → GPIO 14 / 27
 *    LED Place 4 R/G    → GPIO 25 / 33
 *    Buzzer 1           → GPIO 15
 *    Buzzer 2           → GPIO 4
 * ============================================================
 */

#include <Arduino.h>
#include <WiFi.h>
#include <WebServer.h>
#include <ESP32Servo.h>
#include <ArduinoJson.h>

// ─── CONFIG RÉSEAU ───────────────────────────────────────────
#define AP_SSID      "ParkingCam"
#define AP_PASSWORD  "12345678"
IPAddress local_IP(192, 168, 4, 3);
IPAddress gateway(192, 168, 4, 1);
IPAddress subnet(255, 255, 255, 0);

// ─── PINS SERVOS ─────────────────────────────────────────────
#define SERVO_ENTREE_PIN  12
#define SERVO_SORTIE_PIN  13

// ─── ANGLES SERVOS ───────────────────────────────────────────
#define SERVO_OUVERT_ENTREE   90  // verticale = barrière levée
#define SERVO_FERME_ENTREE   180  // horizontale = barrière fermée
#define SERVO_OUVERT_SORTIE  180  // barrière sortie levée vers le haut
#define SERVO_FERME_SORTIE    90  // barrière sortie fermée horizontale

// ─── PINS LEDs RGB ───────────────────────────────────────────
#define LED1_R  18
#define LED1_G  19
#define LED2_R  22
#define LED2_G  23
#define LED3_R  14
#define LED3_G  27
#define LED4_R  25
#define LED4_G  33

// ─── PINS BUZZERS ────────────────────────────────────────────
#define BUZZER_1  15
#define BUZZER_2   4

// ─── DURÉE BUZZER (ms) ───────────────────────────────────────
#define BUZZER_DURATION  500

// ─────────────────────────────────────────────────────────────

Servo servoEntree;
Servo servoSortie;
WebServer server(80);

String ledState[4] = {"green", "green", "green", "green"};

// ─── UTILITAIRES LEDs ────────────────────────────────────────
int getLedRPin(int place) {
  switch (place) {
    case 1: return LED1_R;
    case 2: return LED2_R;
    case 3: return LED3_R;
    case 4: return LED4_R;
    default: return -1;
  }
}

int getLedGPin(int place) {
  switch (place) {
    case 1: return LED1_G;
    case 2: return LED2_G;
    case 3: return LED3_G;
    case 4: return LED4_G;
    default: return -1;
  }
}

void setLed(int place, String color) {
  int pinR = getLedRPin(place);
  int pinG = getLedGPin(place);
  if (pinR == -1 || pinG == -1) return;

  if (color == "red") {
    digitalWrite(pinR, HIGH);
    digitalWrite(pinG, LOW);
  } else if (color == "green") {
    digitalWrite(pinR, LOW);
    digitalWrite(pinG, HIGH);
  } else if (color == "yellow") {
    digitalWrite(pinR, HIGH);
    digitalWrite(pinG, HIGH);
  } else if (color == "off") {
    digitalWrite(pinR, LOW);
    digitalWrite(pinG, LOW);
  }
  ledState[place - 1] = color;
}

// ─── HANDLERS HTTP ───────────────────────────────────────────

// POST /servo-open
void handleServoOpen() {
  if (server.method() != HTTP_POST) {
    server.send(405, "application/json", "{\"error\":\"Method not allowed\"}");
    return;
  }

  StaticJsonDocument<128> doc;
  DeserializationError err = deserializeJson(doc, server.arg("plain"));
  if (err) {
    server.send(400, "application/json", "{\"error\":\"JSON invalide\"}");
    return;
  }

  String servo = doc["servo"] | "";
  if (servo == "entree") {
    servoEntree.write(SERVO_OUVERT_ENTREE);
    Serial.println("[Servo] Barriere ENTREE -> ouverte");
    server.send(200, "application/json", "{\"status\":\"ok\",\"servo\":\"entree\",\"position\":\"ouvert\"}");
  } else if (servo == "sortie") {
    servoSortie.write(SERVO_OUVERT_SORTIE);
    Serial.println("[Servo] Barriere SORTIE -> ouverte");
    server.send(200, "application/json", "{\"status\":\"ok\",\"servo\":\"sortie\",\"position\":\"ouvert\"}");
  } else {
    server.send(400, "application/json", "{\"error\":\"Valeur servo invalide. Utiliser: entree ou sortie\"}");
  }
}

// POST /servo-close
void handleServoClose() {
  if (server.method() != HTTP_POST) {
    server.send(405, "application/json", "{\"error\":\"Method not allowed\"}");
    return;
  }

  StaticJsonDocument<128> doc;
  DeserializationError err = deserializeJson(doc, server.arg("plain"));
  if (err) {
    server.send(400, "application/json", "{\"error\":\"JSON invalide\"}");
    return;
  }

  String servo = doc["servo"] | "";
  if (servo == "entree") {
    servoEntree.write(SERVO_FERME_ENTREE);
    Serial.println("[Servo] Barriere ENTREE -> fermee");
    server.send(200, "application/json", "{\"status\":\"ok\",\"servo\":\"entree\",\"position\":\"ferme\"}");
  } else if (servo == "sortie") {
    servoSortie.write(SERVO_FERME_SORTIE);
    Serial.println("[Servo] Barriere SORTIE -> fermee");
    server.send(200, "application/json", "{\"status\":\"ok\",\"servo\":\"sortie\",\"position\":\"ferme\"}");
  } else {
    server.send(400, "application/json", "{\"error\":\"Valeur servo invalide. Utiliser: entree ou sortie\"}");
  }
}

// POST /led
void handleLed() {
  if (server.method() != HTTP_POST) {
    server.send(405, "application/json", "{\"error\":\"Method not allowed\"}");
    return;
  }

  StaticJsonDocument<128> doc;
  DeserializationError err = deserializeJson(doc, server.arg("plain"));
  if (err) {
    server.send(400, "application/json", "{\"error\":\"JSON invalide\"}");
    return;
  }

  int    place = doc["place"] | 0;
  String color = doc["color"] | "";

  if (place < 1 || place > 4) {
    server.send(400, "application/json", "{\"error\":\"place doit etre entre 1 et 4\"}");
    return;
  }
  if (color != "red" && color != "green" && color != "yellow" && color != "off") {
    server.send(400, "application/json", "{\"error\":\"color doit etre red, green, yellow ou off\"}");
    return;
  }

  setLed(place, color);
  Serial.print("[LED] Place "); Serial.print(place);
  Serial.print(" -> "); Serial.println(color);

  String response = "{\"status\":\"ok\",\"place\":" + String(place) + ",\"color\":\"" + color + "\"}";
  server.send(200, "application/json", response);
}

// POST /buzzer
void handleBuzzer() {
  if (server.method() != HTTP_POST) {
    server.send(405, "application/json", "{\"error\":\"Method not allowed\"}");
    return;
  }

  StaticJsonDocument<128> doc;
  DeserializationError err = deserializeJson(doc, server.arg("plain"));
  if (err) {
    server.send(400, "application/json", "{\"error\":\"JSON invalide\"}");
    return;
  }

  int id       = doc["id"]       | 1;
  int duration = doc["duration"] | BUZZER_DURATION;

  if (id != 1 && id != 2) {
    server.send(400, "application/json", "{\"error\":\"id doit etre 1 ou 2\"}");
    return;
  }

  int pin = (id == 1) ? BUZZER_1 : BUZZER_2;

  server.send(200, "application/json",
    "{\"status\":\"ok\",\"buzzer\":" + String(id) + ",\"duration\":" + String(duration) + "}");

  tone(pin, 1000, duration);
  delay(duration + 50);
  noTone(pin);

  Serial.print("[Buzzer] Buzzer "); Serial.print(id);
  Serial.print(" -> "); Serial.print(duration); Serial.println("ms");
}

// GET /status
void handleStatus() {
  String json = "{";
  json += "\"servos\":{";
  json += "\"entree\":" + String(servoEntree.read() == SERVO_OUVERT_ENTREE ? "\"ouvert\"" : "\"ferme\"") + ",";
  json += "\"sortie\":" + String(servoSortie.read() == SERVO_OUVERT_SORTIE ? "\"ouvert\"" : "\"ferme\"");
  json += "},";
  json += "\"leds\":{";
  json += "\"place1\":\"" + ledState[0] + "\",";
  json += "\"place2\":\"" + ledState[1] + "\",";
  json += "\"place3\":\"" + ledState[2] + "\",";
  json += "\"place4\":\"" + ledState[3] + "\"";
  json += "}";
  json += "}";
  server.send(200, "application/json", json);
}

// GET /test
void handleTest() {
  server.send(200, "text/plain", "ESP32 Actionneurs OK");
}

// 404
void handleNotFound() {
  server.send(404, "application/json", "{\"error\":\"Route non trouvee\"}");
}

// ─── SETUP ───────────────────────────────────────────────────
void setup() {
  Serial.begin(115200);
  Serial.println("\n=== ESP32 Actionneurs Boot ===");

  // ── LEDs RGB ──
  int ledPins[] = {LED1_R, LED1_G, LED2_R, LED2_G,
                   LED3_R, LED3_G, LED4_R, LED4_G};
  for (int pin : ledPins) {
    pinMode(pin, OUTPUT);
    digitalWrite(pin, LOW);
  }
  for (int i = 1; i <= 4; i++) setLed(i, "green");
  Serial.println("[LED] Toutes les places -> vert");

  // ── Buzzers ──
  pinMode(BUZZER_1, OUTPUT);
  pinMode(BUZZER_2, OUTPUT);
  digitalWrite(BUZZER_1, LOW);
  digitalWrite(BUZZER_2, LOW);
  Serial.println("[Buzzer] Initialises");

  // ── Servos ──
  ESP32PWM::allocateTimer(0);
  ESP32PWM::allocateTimer(1);
  servoEntree.setPeriodHertz(50);
  servoSortie.setPeriodHertz(50);
  servoEntree.attach(SERVO_ENTREE_PIN, 500, 2400);
  servoSortie.attach(SERVO_SORTIE_PIN, 500, 2400);
  servoEntree.write(SERVO_FERME_ENTREE);
  servoSortie.write(SERVO_FERME_SORTIE);
  Serial.println("[Servo] Barrieres -> fermees");

  // ── WiFi ──
  WiFi.mode(WIFI_STA);
  WiFi.config(local_IP, gateway, subnet);
  WiFi.begin(AP_SSID, AP_PASSWORD);

  Serial.print("[WiFi] Connexion a ParkingCam");
  int attempts = 0;
  while (WiFi.status() != WL_CONNECTED && attempts < 20) {
    delay(500);
    Serial.print(".");
    attempts++;
  }

  if (WiFi.status() == WL_CONNECTED) {
    Serial.println("\n[WiFi] Connecte");
    Serial.print("[WiFi] IP : ");
    Serial.println(WiFi.localIP().toString().c_str());
  } else {
    Serial.println("\n[WiFi] Connexion echouee — verifier que ParkingCam est actif");
  }

  // ── Routes HTTP ──
  server.on("/servo-open",  HTTP_POST, handleServoOpen);
  server.on("/servo-close", HTTP_POST, handleServoClose);
  server.on("/led",         HTTP_POST, handleLed);
  server.on("/buzzer",      HTTP_POST, handleBuzzer);
  server.on("/status",      HTTP_GET,  handleStatus);
  server.on("/test",        HTTP_GET,  handleTest);
  server.onNotFound(handleNotFound);
  server.begin();

  Serial.println("[HTTP] Serveur demarre");
  Serial.println("  POST /servo-open   {\"servo\":\"entree\"|\"sortie\"}");
  Serial.println("  POST /servo-close  {\"servo\":\"entree\"|\"sortie\"}");
  Serial.println("  POST /led          {\"place\":1-4,\"color\":\"red\"|\"green\"|\"yellow\"|\"off\"}");
  Serial.println("  POST /buzzer       {\"id\":1-2,\"duration\":500}");
  Serial.println("  GET  /status");
  Serial.println("  GET  /test");
  Serial.println("==============================");
}

// ─── LOOP ────────────────────────────────────────────────────
void loop() {
  server.handleClient();
}

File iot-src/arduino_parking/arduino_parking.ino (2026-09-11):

/*
 * ============================================================
 *  Arduino UNO R4 Wifi — Logique Centrale Parking
 *  VERSION STABLE — Sans communication Symfony
 *
 *  Réseau : Se connecte au réseau "ParkingCam" (ESP32 existante)
 *  IP     : 192.168.4.2 (fixe)
 *
 *  Routes disponibles :
 *    POST /open  → ouvre la barrière entrée (appelé par Python)
 *
 *  Dépendances :
 *    → ESP32 nouvelle  : 192.168.4.3 (actionneurs)
 *    → ESP32 existante : 192.168.4.1 (réseau ParkingCam)
 *
 *  Branchements HC-SR04 :
 *    Place 1    → TRIG:D2  ECHO:D3
 *    Place 2    → TRIG:D4  ECHO:D5
 *    Place 3    → TRIG:D6  ECHO:D7
 *    Place 4    → TRIG:D8  ECHO:D9
 *    Barrière   → TRIG:D10 ECHO:D11
 *
 *  LCD I2C :
 *    SDA → A4 | SCL → A5
 * ============================================================
 */

#include <Arduino.h>
#include <WiFiS3.h>
#include <WiFiClient.h>
#include <Wire.h>
#include <LiquidCrystal_I2C.h>

// ─── CONFIG RÉSEAU ───────────────────────────────────────────
#define AP_SSID      "ParkingCam"
#define AP_PASSWORD  "12345678"

IPAddress local_IP(192, 168, 4, 2);
IPAddress gateway(192, 168, 4, 1);
IPAddress subnet(255, 255, 255, 0);

const char* ESP32_IP   = "192.168.4.3";
const int   ESP32_PORT = 80;

// ─── PINS HC-SR04 ────────────────────────────────────────────
#define TRIG_P1  2
#define ECHO_P1  3
#define TRIG_P2  4
#define ECHO_P2  5
#define TRIG_P3  6
#define ECHO_P3  7
#define TRIG_P4  8
#define ECHO_P4  9
#define TRIG_BAR 10
#define ECHO_BAR 11

// ─── SEUILS DÉTECTION ────────────────────────────────────────
#define SEUIL_PLACE    3
#define SEUIL_BARRIERE 3

// ─── TIMING ──────────────────────────────────────────────────
#define DELAI_SCAN        50
#define DUREE_BARRIERE   3000
#define BUZZER_DURATION   500
#define COOLDOWN_BARRIERE 5000

// ─── LCD ─────────────────────────────────────────────────────
LiquidCrystal_I2C lcd(0x27, 16, 2);

// ─── ÉTAT DES PLACES ─────────────────────────────────────────
bool placeOccupee[4]          = {false, false, false, false};
bool barriereSortieOuverte    = false;
unsigned long dernierOuvertureSortie = 0;
unsigned long dernierScanPlace[4]    = {0, 0, 0, 0};
unsigned long dernierScanBarriere    = 0;

// ─── SERVEUR HTTP ────────────────────────────────────────────
WiFiServer httpServer(80);

// ─────────────────────────────────────────────────────────────

// ─── MESURE DISTANCE HC-SR04 ─────────────────────────────────
float mesurerDistance(int trigPin, int echoPin) {
  digitalWrite(trigPin, LOW);
  delayMicroseconds(2);
  digitalWrite(trigPin, HIGH);
  delayMicroseconds(10);
  digitalWrite(trigPin, LOW);

  long duration = pulseIn(echoPin, HIGH, 30000);
  if (duration == 0) return 999.0;
  return (duration * 0.0343) / 2.0;
}

// ─── ENVOI REQUÊTE HTTP vers ESP32 nouvelle ──────────────────
bool envoyerRequete(String route, String body) {
  WiFiClient client;

  if (!client.connect(ESP32_IP, ESP32_PORT)) {
    client.stop();
    return false;
  }

  client.println("POST " + route + " HTTP/1.1");
  client.println("Host: " + String(ESP32_IP));
  client.println("Content-Type: application/json");
  client.println("Content-Length: " + String(body.length()));
  client.println("Connection: close");
  client.println();
  client.println(body);

  unsigned long timeout = millis() + 500;
  while (client.available() == 0 && millis() < timeout);

  String statusLine = "";
  if (client.available()) {
    statusLine = client.readStringUntil('\n');
  }

  while (client.available()) client.read();
  client.stop();

  bool ok = statusLine.indexOf("200") >= 0;
  Serial.print("[HTTP] "); Serial.print(route);
  Serial.print(" -> "); Serial.println(ok ? "200 OK" : "ERREUR");
  return ok;
}

// ─── COMMANDES ESP32 NOUVELLE ────────────────────────────────
void ouvrirBarriere(String servo) {
  envoyerRequete("/servo-open", "{\"servo\":\"" + servo + "\"}");
  int buzzerId = (servo == "entree") ? 1 : 2;
  envoyerRequete("/buzzer",
    "{\"id\":" + String(buzzerId) + ",\"duration\":" + String(BUZZER_DURATION) + "}");
  Serial.print("[Barriere] "); Serial.print(servo); Serial.println(" -> ouverte");
}

void fermerBarriere(String servo) {
  envoyerRequete("/servo-close", "{\"servo\":\"" + servo + "\"}");
  Serial.print("[Barriere] "); Serial.print(servo); Serial.println(" -> fermee");
}

void setLedPlace(int place, String color) {
  envoyerRequete("/led",
    "{\"place\":" + String(place) + ",\"color\":\"" + color + "\"}");
  Serial.print("[LED] Place "); Serial.print(place);
  Serial.print(" -> "); Serial.println(color);
}

// ─── MISE À JOUR LCD ─────────────────────────────────────────
void mettreAJourLCD() {
  int placesLibres = 0;
  for (int i = 0; i < 4; i++) {
    if (!placeOccupee[i]) placesLibres++;
  }

  lcd.clear();
  lcd.setCursor(0, 0);
  lcd.print("Parking DaVinci");
  lcd.setCursor(0, 1);

  if (placesLibres == 0) {
    lcd.print("COMPLET         ");
  } else {
    lcd.print("Libres: ");
    lcd.print(placesLibres);
    lcd.print("/4      ");
  }
}

// ─── GESTION REQUÊTES HTTP ENTRANTES ─────────────────────────
void gererRequetesEntrantes() {
  WiFiClient client = httpServer.available();
  if (!client) return;

  unsigned long timeout = millis() + 500;
  String requestLine = "";

  while (client.connected() && millis() < timeout) {
    if (client.available()) {
      char c = client.read();
      requestLine += c;
      if (requestLine.endsWith("\r\n\r\n")) break;
    }
  }

  Serial.println("[HTTP] Requete recue");

  if (requestLine.startsWith("POST /open")) {
    client.println("HTTP/1.1 200 OK");
    client.println("Content-Type: application/json");
    client.println("Connection: close");
    client.println();
    client.println("{\"status\":\"ok\",\"duration_ms\":" + String(DUREE_BARRIERE) + "}");
    client.stop();

    ouvrirBarriere("entree");
    delay(DUREE_BARRIERE);
    fermerBarriere("entree");

  } else {
    client.println("HTTP/1.1 404 Not Found");
    client.println("Connection: close");
    client.println();
    client.println("{\"error\":\"Route non trouvee\"}");
    client.stop();
  }
}

// ─── SCAN DES PLACES ─────────────────────────────────────────
void scannerPlaces() {
  int trigPins[] = {TRIG_P1, TRIG_P2, TRIG_P3, TRIG_P4};
  int echoPins[] = {ECHO_P1, ECHO_P2, ECHO_P3, ECHO_P4};

  for (int i = 0; i < 4; i++) {
    if (millis() - dernierScanPlace[i] < DELAI_SCAN) continue;
    dernierScanPlace[i] = millis();

    float dist   = mesurerDistance(trigPins[i], echoPins[i]);
    bool occupee = (dist < SEUIL_PLACE);

    Serial.print("[HC-SR04] Place "); Serial.print(i + 1);
    Serial.print(" : "); Serial.print(dist);
    Serial.print(" cm -> "); Serial.println(occupee ? "OCCUPEE" : "libre");

    if (occupee != placeOccupee[i]) {
      placeOccupee[i] = occupee;
      setLedPlace(i + 1, occupee ? "red" : "green");
      mettreAJourLCD();
    }
  }
}
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
